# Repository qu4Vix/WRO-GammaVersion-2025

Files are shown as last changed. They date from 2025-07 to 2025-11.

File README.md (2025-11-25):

# WRO 2025 GammaVersion’s repository
**This is our repository for the 2025 season of the WRO Future Engineer Challenge**

***
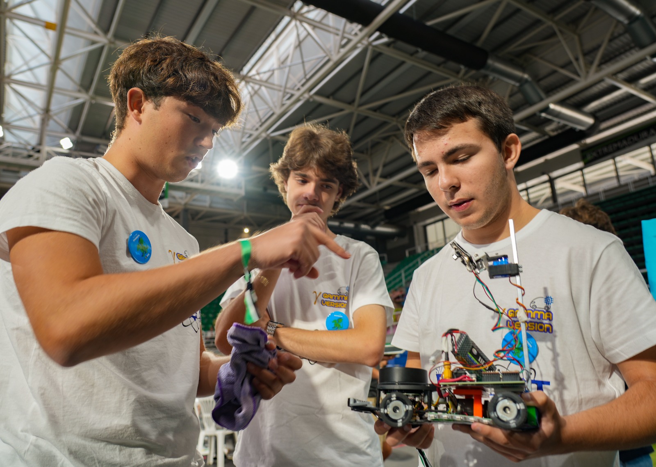
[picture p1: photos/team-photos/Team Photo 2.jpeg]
Picture of our team in the 2025 Spanish National Final


## TABLE OF CONTENTS

* [Hardware](#hardware)
    * [Car movement](#car-movement)
    * [Structural design](#structural-design)

* [Electronics and sensors](#electronics-and-sensors)
    * [List of components](#list-of-components)
    * [Sensor list](#sensor-list)
    * [Power Management](#power-management)
    * [PCB](#pcb)

* [Strategy and operation of the code](#strategy-and-operation-of-the-code)
    * [Slave code](#how-the-slave-code-works)
    * [Location of the robot](#location-of-the-robot-on-the-board)
    * [Open Challenge Strategy](#open-challenge-strategy)
    * [Obstacle Challenge Strategy](#obstacle-challenge-strategy)

* [Photos](#photos)
    * [Car images](#car-images)
    * [Team images](#team-images)

* [Demostration videos](#demonstration-videos)

* [License](#license)

* [Credits](#credits)

* [Contact and Social Media](#contact-and-social-media)
  
Gif Bueno 2

## HARDWARE

Designing a self-driving car for these challenges requires a meticulous design process to achieve an optimal final result that meets the needs of the challenge and the potential obstacles that may arise during the programming process and the competition itself.

In our case, in order to reduce development times and finding it more feasible and simple to rely on existing resources than having to design a new chassis from scratch, we decided to use a remote-controlled car kit that we then modified extensively to adapt it to our particular needs.

### Car movement

We can highlight as the main modification the redesign of the turning system to allow tighter turns, since the original kit was deficient in this aspect and forced us to have to maneuver to be able to turn correctly during the competition and, although this is contemplated in the regulations, it made us lose a lot of time and increased the total complexity of the strategy. The redesign required the creation of new parts that have been designed by ourselves and whose 3D files can be found in our repository in the section [`robot-info`](/robot-info/).We have printed these parts with our 3D printer, which also reduces costs and allows us to easily create different versions if we see that they fail or not.

With these changes to the turning system we have implemented the **Ackerman's Steering Geometry**,this mechanism allows the turning wheels to take different paths when turning, since the turning radius of the inner wheel is smaller than that of the outer wheel, thus the angle of each turning wheel is different. This implementation allows for better turning, and with certain tweaks, we have minimized the required turning radius. This mechanism is actuated by a generic servo **DSM44 Servo**. It has the necessary torque and speed without being a problem in terms of power consumption. In the following images, we can see the nature of why this mechanism is necessary, a simplified version of how it works, and our design of the mechanism for our robot.

| | |
| --- | --- |
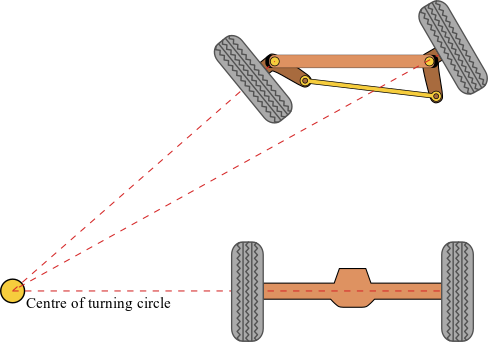
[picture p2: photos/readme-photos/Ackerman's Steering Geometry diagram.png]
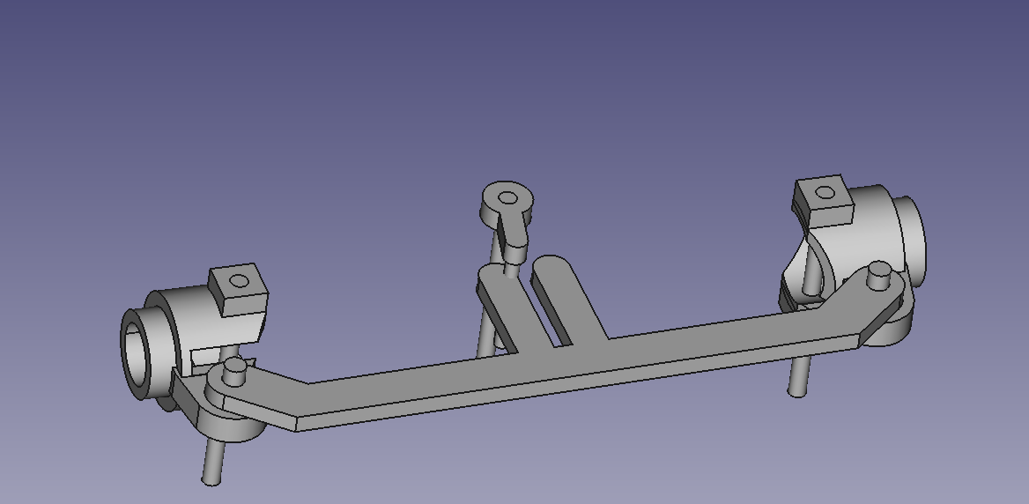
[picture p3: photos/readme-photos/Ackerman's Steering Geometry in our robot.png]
|  |  |

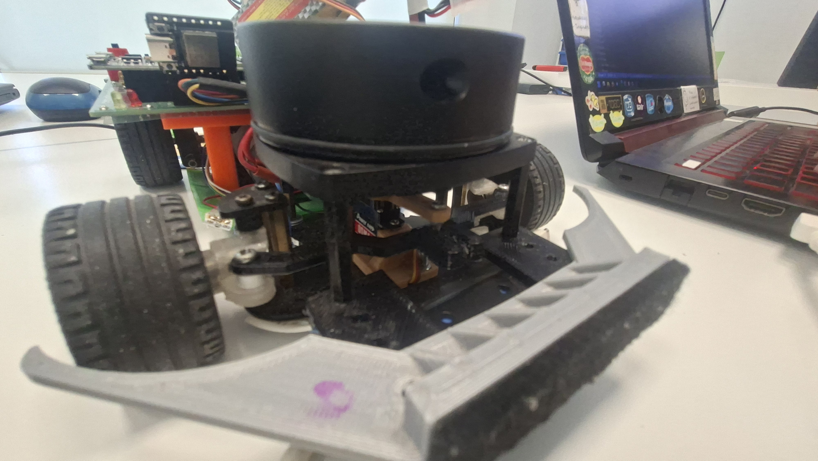
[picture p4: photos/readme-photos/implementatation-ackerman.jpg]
Car front view of the steering design


More information about Ackerman's Steering Geometry can be found in [this Wikipedia article](https://en.wikipedia.org/wiki/Ackermann_steering_geometry).

According to competition regulations, only one motor can drive a drive axle. Therefore, in our case, we made the rear axle the drive axle to which the motor is connected. This is how the original kit was made. We also used the differential that came with the kit for proper operation. The differential allows the rear wheels to travel different distances, since the arc that each wheel travels is different when turning, as the turning radius of each wheel also varies. For our robot, we also used the motor that came with the kit; you can see the image below.

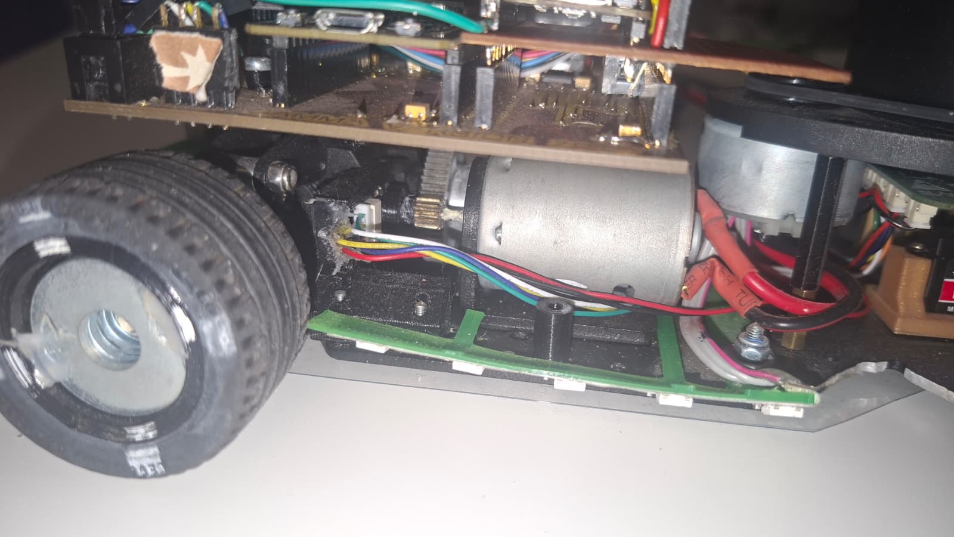
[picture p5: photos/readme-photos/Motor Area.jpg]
Side view of the motor


This motor provides us with the necessary torque to comfortably move the robot without it getting stuck. In our case, we're not trying to get the robot to go at maximum speed, so the robot's overall speed wasn't a relevant factor when choosing the motor.

### Structural design

As we can see in this image, the robot needs to accommodate a variety of different sensors in its limited space. This required a proper structural design beyond the kit's chassis, which is the lower black part of the robot.

First of all, we can distinguish the **LiDAR** Located on the front of the robot, this component rests on the chassis and is bolted to it. It also connects to a front bumper that protects the components in the event of a collision during testing or competition.

Secondly, below the LiDAR is the space needed to place the components of the **Ackerman's Steering Geometry** and the **servo** in charge of turning the wheels.

Thirdly, at the rear we can see from above the **PCB**, which houses much of our car's electronics, further on in [PCB](#pcb) we detail its design. Just below the PCB is the **motor** and the **differential** that drives the drive axle.

Finally, at the rear, the metal mast that raises and holds our **camera** is held on a 3D-designed base to the vehicle.

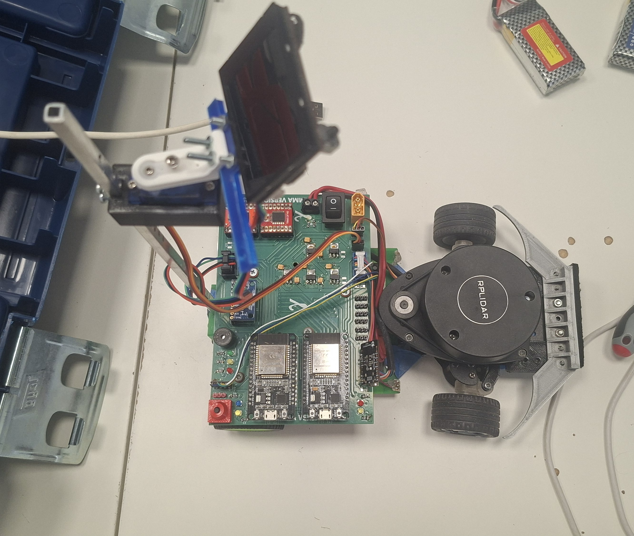
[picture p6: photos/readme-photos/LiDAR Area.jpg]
Top view of the car


## ELECTRONICS AND SENSORS

Our robot is made up of a whole series of electronic components and sensors that work together to provide us with the best possible information so we can perform our tasks. We must emphasize the use of information from multiple sensors simultaneously to reduce errors.

Below we provide a detailed list of all the electronic components that make up the car, along with a detailed description of their functionality and the advantages that led us to use them.

### List of components

* DOIT ESP32 DevKit V1 x2
* HuskyLens
* RPLiDAR A1 M8
* MPU 9250
* Pololu Magnetic Encoder
* DSM44 Servo
* Motor Driver x2
* Power Supply x3
* RGB LEDs
* White LED flashlight

#### Esp-32 (Microcontroller)

To bring our autonomous car project to fruition, we opted for the ESP-32 microcontroller as the central control unit. The ESP-32 boasts several compelling advantages that played a pivotal role in our decision-making process:

1. Computing Power and Versatility: The ESP-32 distinguishes itself with its robust computational capabilities and remarkable versatility. Equipped with a potent dual-core processor and ample memory capacity, it emerged as the natural choice for our robotics endeavor, enabling rapid computation and accommodating our storage needs seamlessly.

2. Advanced Wireless Connectivity: The ESP-32 integrates cutting-edge Wi-Fi and Bluetooth connectivity, positioning it as a frontrunner for efficient wireless communication. This capability empowered us to establish seamless and reliable communication channels between the autonomous car and external devices, a really useful feature for our debugging needs. However, wireless connectivity is forbidden during the competition and we disable this option before the match.

3. Sensor and Actuator Compatibility: The ESP-32's adaptability extends to sensor and actuator integration. With its multitude of I/O (input/output) pins and versatile interface options, we effortlessly connected and controlled various sensors, including the IMU and LiDAR, as well as the steering servos.

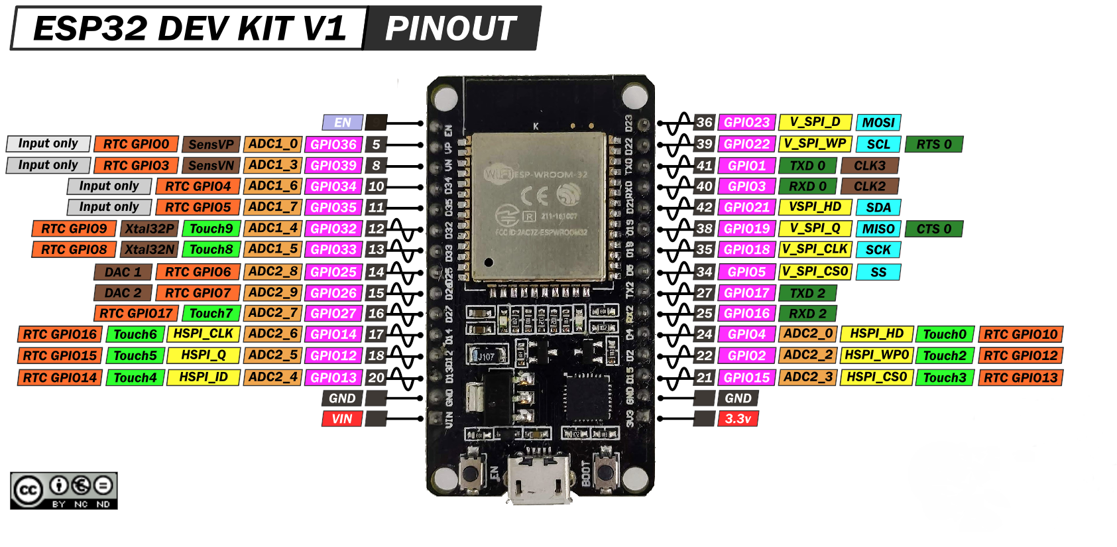
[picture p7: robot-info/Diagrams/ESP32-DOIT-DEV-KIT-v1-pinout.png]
Pinout of the ESP32 DevKit V1


We integrated two ESP32s into our robot, as it was necessary due to the large amount of information they must analyze from all the sensors and the decisions they must make. For this purpose, we call one ESP32 "Slave," to which several sensors are connected. After analyzing this information, it sends it to another ESP32, which we call "Master." Other sensors are connected to this ESP32, and it is responsible for executing all the movement commands.

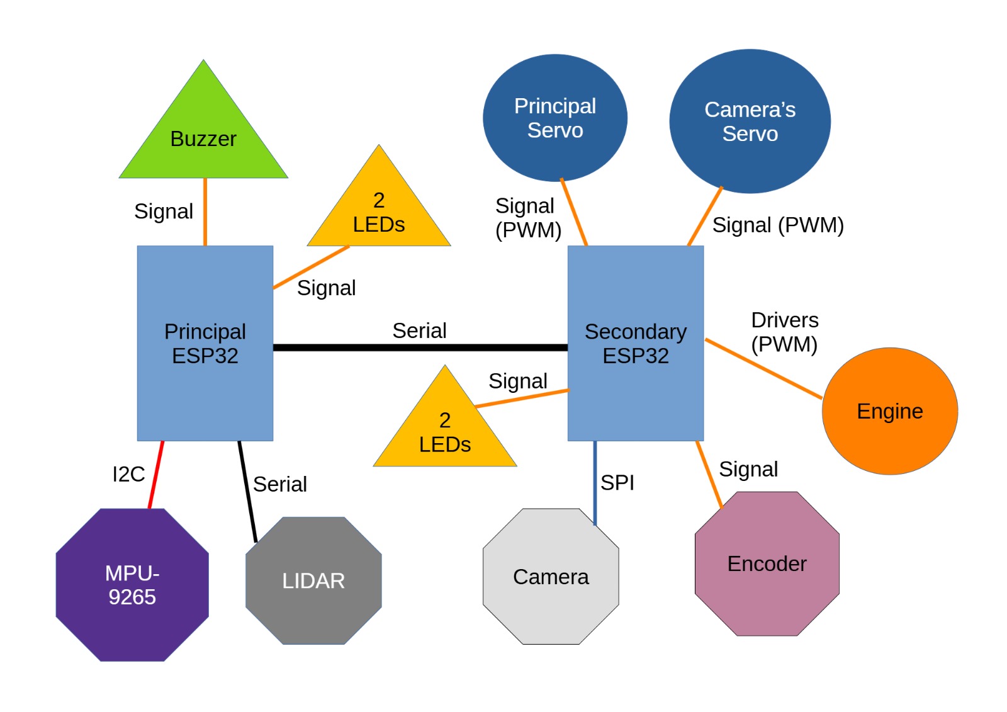
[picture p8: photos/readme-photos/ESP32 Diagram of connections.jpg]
Connection diagram


#### HuskyLens (Camera)

The HuskyLens camera was our choice because it gives us a larger horizontal field of view compared to other available cameras and also incorporates several algorithmic options to be able to detect a wide variety of things, such as distinguishing colors, people, objects, codes, etc. We also chose it because of its improved data processing capacity, which is superior to the alternatives we had locally and which also allows us to train it much better than other cameras, thus guaranteeing a great improvement in precision and allowing us to adjust to the lighting conditions of the competition venue.

The camera's sole function is to detect the colored blocks, indicate their position on the camera, and indicate their color. We train it for all of this before the competition.

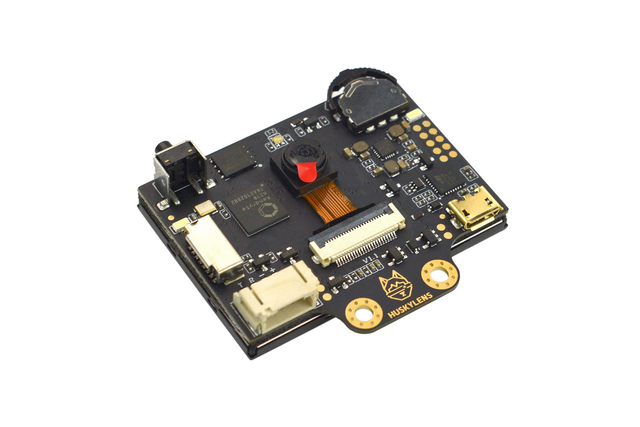
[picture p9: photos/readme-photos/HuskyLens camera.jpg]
Image of a HUSKY Lens


#### RPLiDAR A1 M8 (LiDAR)

Rather than relying on traditional ultrasonic sensors for obstacle detection, we opted for LiDAR technology. LiDAR, which stands for Light Detection and Ranging, uses laser beams to measure distances to objects with exceptional precision. This technology offers several advantages over ultrasonic sensors:

1. Greater Range: LiDAR can detect objects at much greater distances, providing the car with more time to react to potential obstacles.

2. High Precision: LiDAR provides accurate distance measurements, resulting in better navigation and collision avoidance.

3. 360-Degree Coverage: LiDAR offers a full 360-degree view around the car, ensuring comprehensive situational awareness.

4. Environmental Adaptability: LiDAR is less affected by environmental factors such as ambient light, making it more reliable in various conditions.

During the match the LiDAR technology is used to establish the initial position of the robot and the direction of the game. In this way the random initial conditions do not affect the outcome of the match.

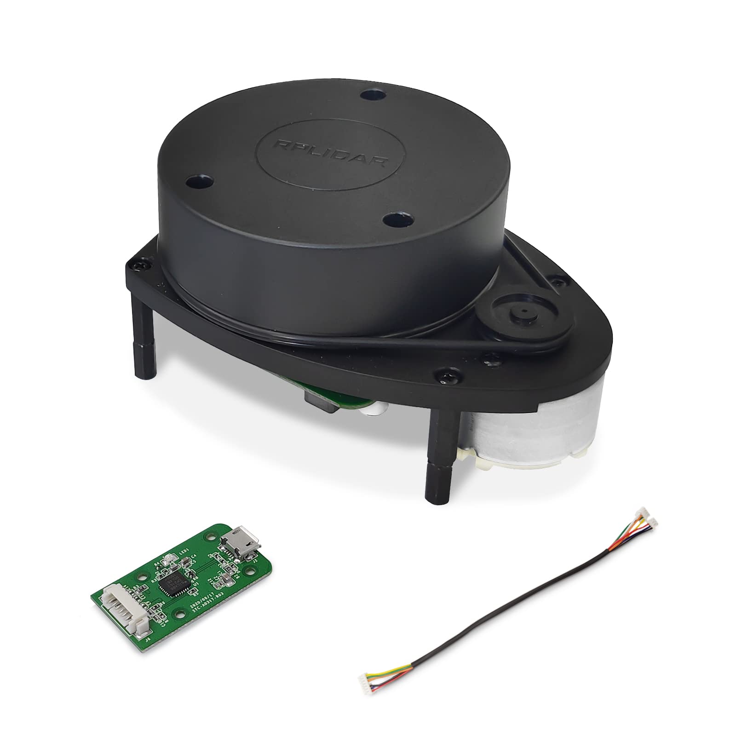
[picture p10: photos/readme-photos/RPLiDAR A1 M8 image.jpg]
Image of an RPLIDAR A1


#### MPU 9250 and Pololu Magnetic Encoder (IMU and encoder)

On one hand, IMU stands for Inertial Measurement Unit, this is a combination of gyroscopes, accelerometers and in our MPU 9250 magnetometers too. On the other hand, a enconder is a system that reads the rotation of the motor or axle and allows us to know how much it has turned, and with some analysis it lets us know the length of the displacement of our robot. Inertial navigation has plenty of disadvantages compared to for example LiDAR navigation, some of its problems are that the precision is worse than LiDAR's and that this system does not really know where the robot is in the real world, only how much it has moved or turned since the start of the program. It might seem that using this technology is a downgrade and unnecessary as we already have the LiDAR, however, the IMU combinated with a encoder gives easier-to-use data compared to the huge amount of information the LiDAR gives us every second.

In our case, we only use our LiDAR to establish which is the initial position of the robot and the direction of the game, but after this the LiDAR is no longer used in the game. Through all the rest of the match only the IMU and encoder are used to follow an imaginary path around the central square in the Open Challenge or around the square and through the traffic signs in the Obstacle Challenge with the color information gived by the camera.

#### White LED flashlight

Shortly before attending the Spanish national final, we observed that in certain situations with changing lighting, our robot could have serious problems distinguishing colors. The fact that our camera is sensitive to light was already known, but we didn't think it would be so problematic at first. However, seeing that it was causing problems and with limited time, we decided to install a white LED light next to the camera so that it would receive video with a constant amount of illumination at all times.

The LED was connected directly to the battery and main power switch, ensuring that the power consumption of the LED  wouldn't negatively impact other more sensitive systems in the robot. To prevent the LED from receiving too much current, several resistors were installed in parallel along the cable.

After the competition, we analyzed that the camera still had occasional problems, and we eventually redesigned the camera's code to avoid these issues. Our robot still has the space and components necessary to reinstall the LED if we deem it necessary during the competition, although, as we have already mentioned, this shouldn't be the case.

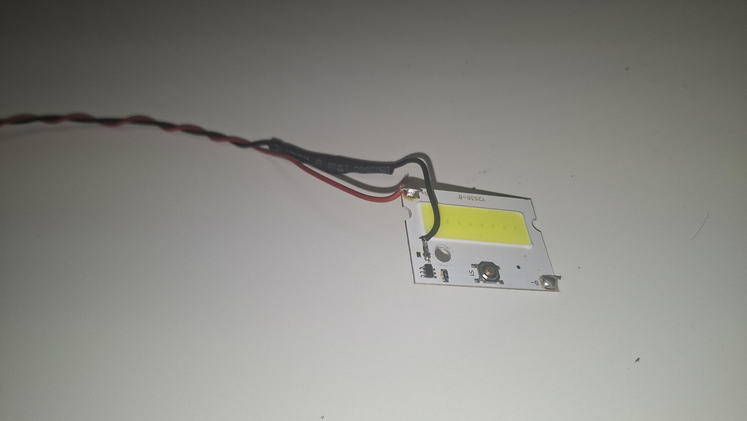
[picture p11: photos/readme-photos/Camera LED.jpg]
Image of the camera's LED lantern


### Sensor list

As we can see, our robot only uses the following sensors, whose data are used in unison by our microcontrollers to maximize reliability and be able to solve the different challenges that this competition poses to us.

* LiDAR
* IMU
* Encoder
* Camera

### Power Management

Our robot is powered by a single 7V battery with a capacity of 1200 mAh, which provides the necessary energy for the robot to function properly. Before building the car, when we were considering which electronic components to choose, we considered the energy consumption of each component and how we could provide the necessary voltage to each element. After analyzing this, we designed the system to adequately meet the energy requirements.

Our PCB contains several power sources that distribute power correctly and efficiently to our sensors and actuators. We can list them as follows:

1. Dual 5-Volt Power Supplies: One 5-volt power supply was dedicated to powering the LiDAR system, while the other supplied power to the steering servos. This separation of power sources allowed us to optimize the energy delivery to these critical components, ensuring their reliable operation.

2. 3.3-Volt Power Supply: A dedicated 3.3-volt power supply was employed to energize the microcontrollers, IMU (Inertial Measurement Unit), motor drivers, and LED lights. This voltage level was carefully chosen to meet the requirements of these electronic components, guaranteeing stable and consistent performance.

By employing these distinct power sources, we effectively managed the power needs of our autonomous car's various subsystems, ensuring that each component received the appropriate voltage and current for reliable operation. This meticulous power management contributed to the overall success and stability of our robotics project.

### PCB

To seamlessly connect and control all the components of our autonomous car, we designed and printed a custom PCB. The PCB acted as the central hub that allowed us to interface with sensors, motors, microcontrollers, and other electronic components efficiently.

Our custom PCB design allowed for cleaner wiring, reduced interference, and enhanced reliability. It simplified the process of connecting and configuring various sensors and actuators, enabling smoother integration and troubleshooting during the development phase.

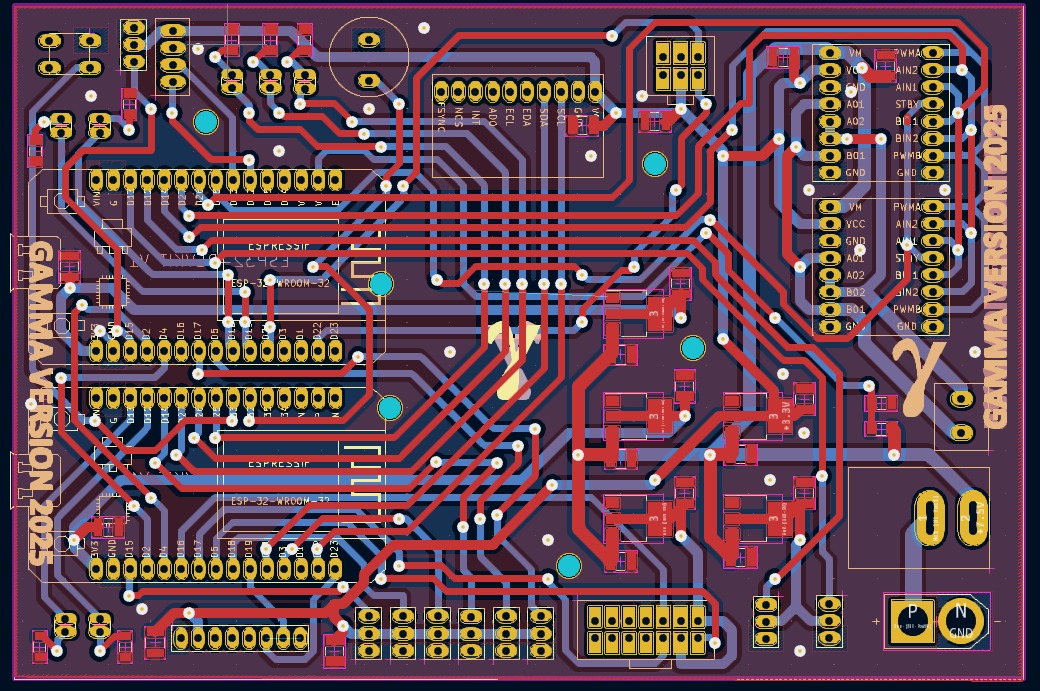
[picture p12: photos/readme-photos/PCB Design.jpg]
Layer design image of the PCB


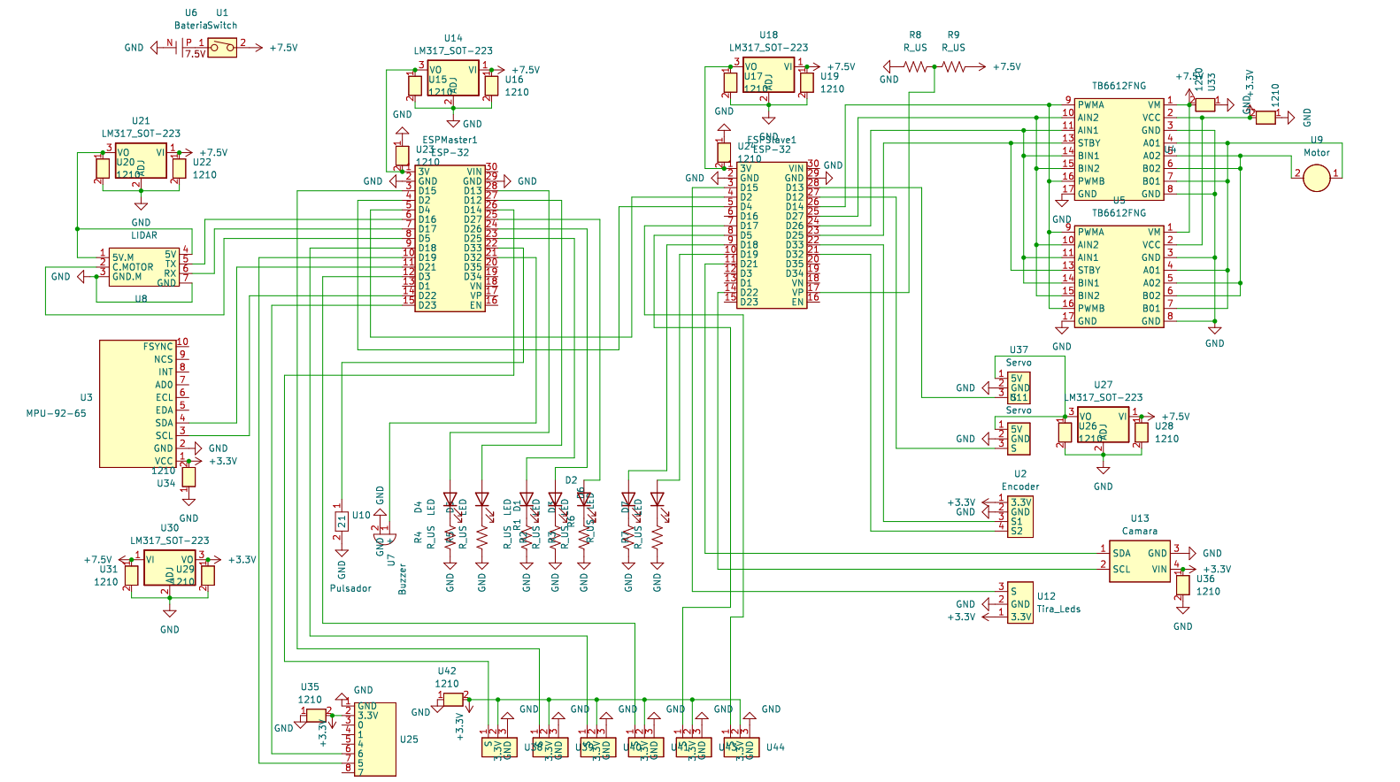
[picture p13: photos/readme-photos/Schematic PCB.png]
Schematic diagram of the circuit


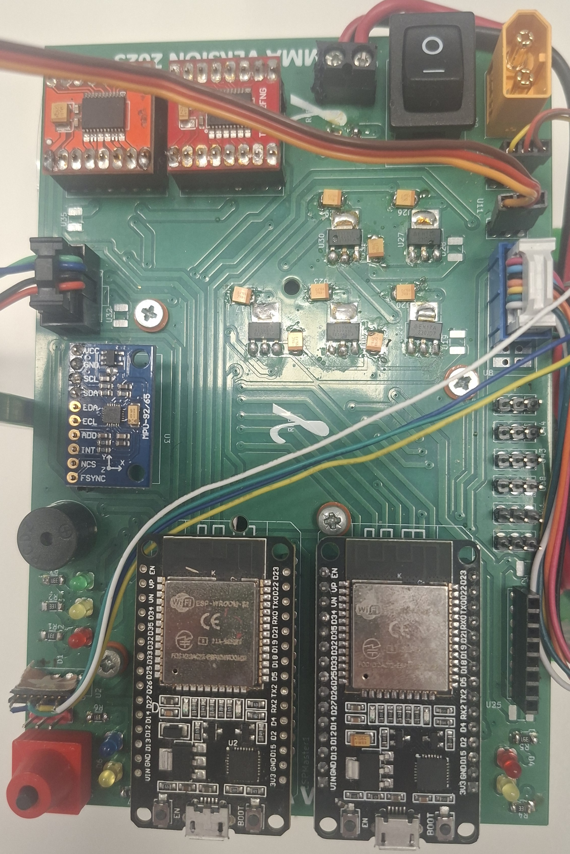
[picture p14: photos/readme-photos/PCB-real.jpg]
Top view of the finished PCB


## STRATEGY AND OPERATION OF THE CODE

As we mentioned before, the code is divided into two parts, one for the ESP32 “Master” and another for the ESP32 “Slave”. In our case, the code for the “Slave” is the same for both types of rounds in the competition, the Open Challenge and the Obstacle Challenge. If you wish, you can activate or deactivate certain functions related to the Obstacle Challenge when not in use by changing a value of a define in the code, although this is not necessary for correct operation.

On the other hand, due to the large variations between the two challenges, we found two separate codes for the ESP32 "Master," one used only in the Open Challenge rounds and the other for the Obstacle Challenge rounds. This gives us two separate codes that allow us to better address the bugs and challenges of each category.

For more information on the code structure and the upload protocol, go to [code](code/README.md).

### How the “Slave” code works

The “Slave” code is responsible for collecting data from various sensors and sending it via serial to the “Master” for processing and analysis. On the other hand, the “Slave” receives data via serial to move the motor and servo from the “Master”.

The "Slave" also has the function of cleaning and filtering the camera information. Due to the way the HuskyLens works, it is very likely that it will mistakenly detect the orange line on the dashboard as if it were a red block, or even detect the parking barriers as red blocks. This is clearly detrimental to the robot's operation and can lead to errors. To avoid these errors, the "Slave" only sends to the "Master" the block that is closest to the camera and that is not a square or a horizontal rectangle (this is because the camera detects objects in squares that encompass the surface of the detected object, not the object's actual shape). This prevents detection errors.

### Location of the robot on the board

To determine the car's exact location on the dashboard, the same system is used in both the Open Challenge and the Obstacle Challenge. The system is based on a coordinate system that places (0,0) in the lower left corner from the car's point of view. To locate the car on the dashboard, two phases occur:

1. From the robot's starting location, the LiDAR measures the distance in a straight line from the robot to the front wall, that is, at an angle of 0° relative to the robot's current direction. With this data, we can determine the robot's current Y-position.

2. The robot then moves forward until it is a certain distance from the front wall that allows it to see to the sides. The robot now measures the distance to its left (270°) and right (90°). With this data, the robot is able to establish its position on the X axis of the coordinate system, and it also allows it to determine the direction of rotation of the circle.

### Open Challenge Strategy

In the Open Challenge, the robot must complete three laps of the circuit from a random starting position and direction and must be able to finish in the same starting section. In addition, the size of the central square varies from round to round, adding additional difficulty.

With the information from the previous paragraph in mind, our strategy is based on correctly determining our position on the board and then completing the circuit from there. Our robot has no knowledge of the size of the central square, as it simply navigates an imaginary circuit that is larger than the maximum limits of the central square, as we can see in the images.

| | |
| --- | --- |
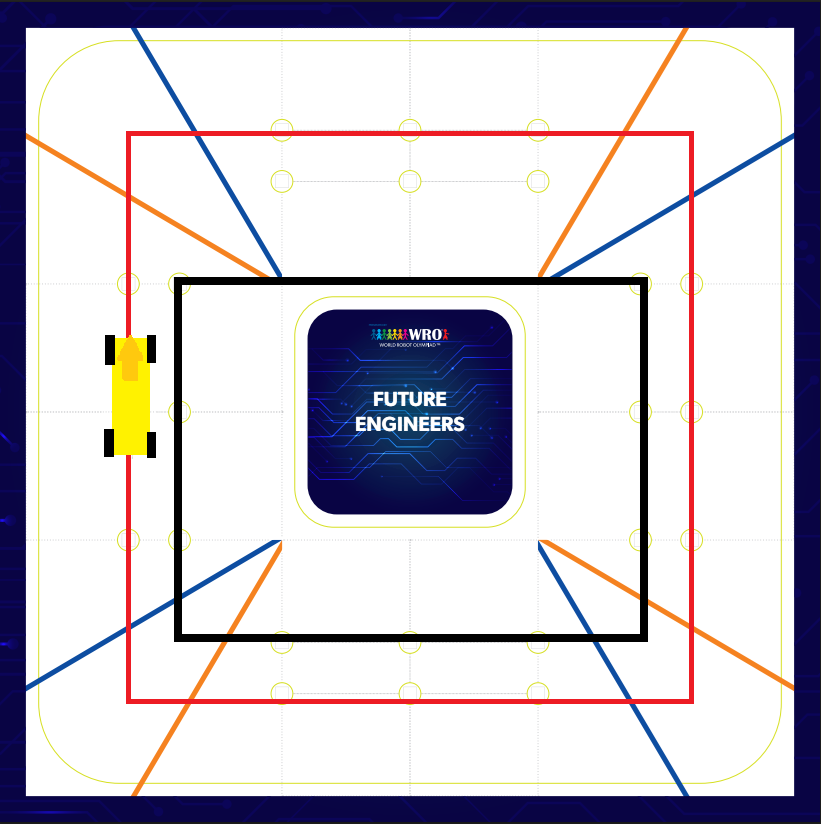
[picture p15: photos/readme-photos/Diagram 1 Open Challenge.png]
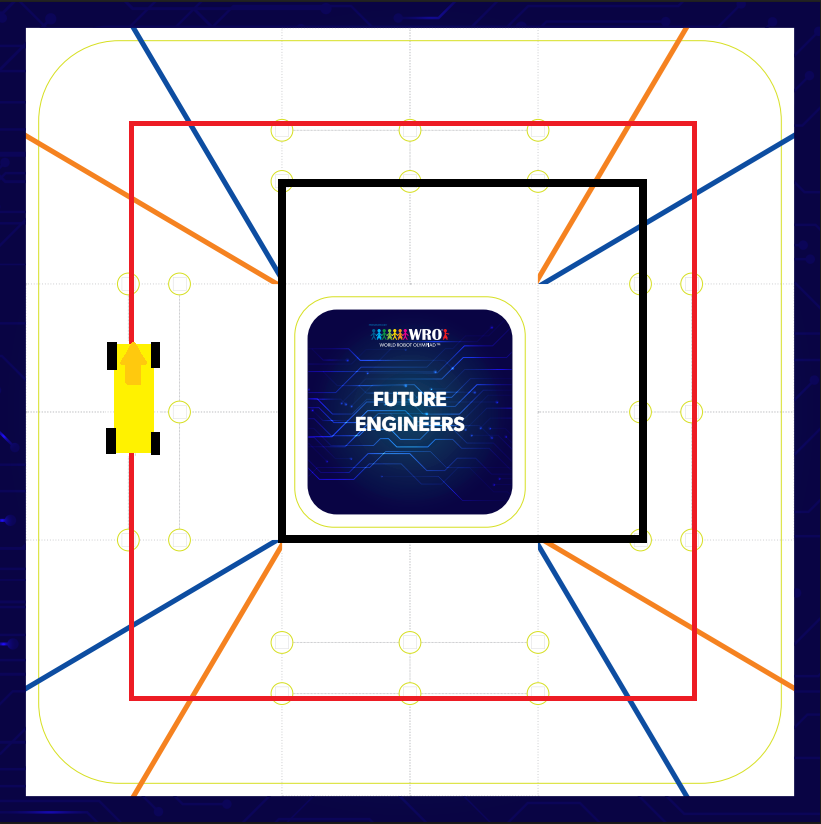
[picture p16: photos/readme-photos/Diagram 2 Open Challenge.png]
|  |  |

### Obstacle Challenge Strategy

The goal in the Obstacle Challenge is for the robot to complete three laps of the circuit, dodging the green blocks or "traffic lights" on the left and the red blocks on the right without colliding with them or making any mistakes. To earn more points, you can optionally start from the parking area (defined by two horizontal barriers) instead of the middle of the board. You can also optionally park inside the parking area, earning even more points if you parallel park.

Our code is designed to always start from the parking area. Therefore, at the beginning of each round, we use LiDAR to measure both sides of the robot (left and right) to determine the greater distance. If the distance is greater to the right than to the left, the robot knows the direction of rotation is clockwise, while if it detects a greater distance to the left, it knows the direction is counterclockwise. Once we know the direction of rotation, we use the distance to the central wall to establish our position on the board, following our own system that we discussed earlier. The algorithm is as follows:

* If (Clockwise == True) PositionX = 1000 – LiDAR_Measurement (90º);
* If (Clockwise == True) PositionX = 2000 + LiDAR_Measurement (270º);

Knowing the X position, the robot is now able to leave the parking area. However, to prevent accidentally passing a traffic light immediately after exiting, the camera's servo motor points directly to where a block might be located, to check for its presence.

Before continuing, it's important to explain several key aspects of how our code works:

* First, we designed a complex and useful automatic movement system where we tell the robot which X and Y position we want it to move to, and it performs the movement on its own. This way, if you look at our code, you'll see that we rarely send commands directly to the motors or the wheel servo, but rather to the movement instructions. The movement is complemented by a PID controller with KD and KP values that we can vary along the robot's path as needed.

* Second, internally we divide the board into four "sections" that represent each non-turning section.
* Third, our robot never considers whether the blocks are in the inner or outer squares; whenever it sees a block, it will avoid it in such a way that it never crosses any square.

Having said that, to exit the parking area, we programmed our motion system to leave by assigning it coordinates located next to the parking lot. Once this was done, we used LiDAR to measure the external barrier above the robot. We used trigonometry so that even if the robot wasn't 100% parallel or perpendicular to the upper barrier, it would still provide correct directions, regardless of whether the robot was slightly tilted relative to the barrier.

If there had been a block upon exiting the parking area, the robot would have avoided it. After exiting and avoiding the block, if necessary, the code would enter the "avoid and learn" state. In this state, the robot completed one lap of the circuit, reading the colors of the blocks with the camera and avoiding them on the correct side.

Because the wide-angle lens of our camera wasn't very good, we decided to install a servo motor underneath the camera to move it and ensure that the camera always pointed where blocks might be. This mechanism is really important for tight turns, where there's a chance that if the camera were fixed, the robot wouldn't see the next block before missing it or crashing.

In this first "state," in addition to reading the camera, the robot is memorizing the position of each traffic light. After completing the first lap, the robot performs the next two laps "from memory," without using the camera at any point. We do this because every time we measure the blocks with the camera, there's a small chance the robot will make a mistake. It's true that it can also make a mistake on the first lap, but if this happens, we would have already finished the lap, as it ends as soon as a mistake is made, according to the regulations. If we haven't stopped after the first lap, it means we already know the position of the traffic lights well, so it's best to perform them from memory instead of continuing to maintain the probability of error.

When the robot reaches the last corner of each lap, it stops, remaining perpendicular to the external barrier in front of it, to recalibrate its position using LiDAR. We didn't originally intend to do this, but after extensive testing, we realized that the IMU and encoder lost accuracy and quality throughout the lap, especially if the robot had to perform many maneuvers.

Finally, after the three laps and the final recalibration, the robot enters "parking" mode. It then slowly approaches the parking position, maneuvers back slowly, and finally parks. In this mode, we significantly increased the turning radius (KP) and turning radius (KD) to maximize the robot's turning capabilities and enable it to park in the limited available space.

## PHOTOS

### Car images

| | |
| --- | --- |
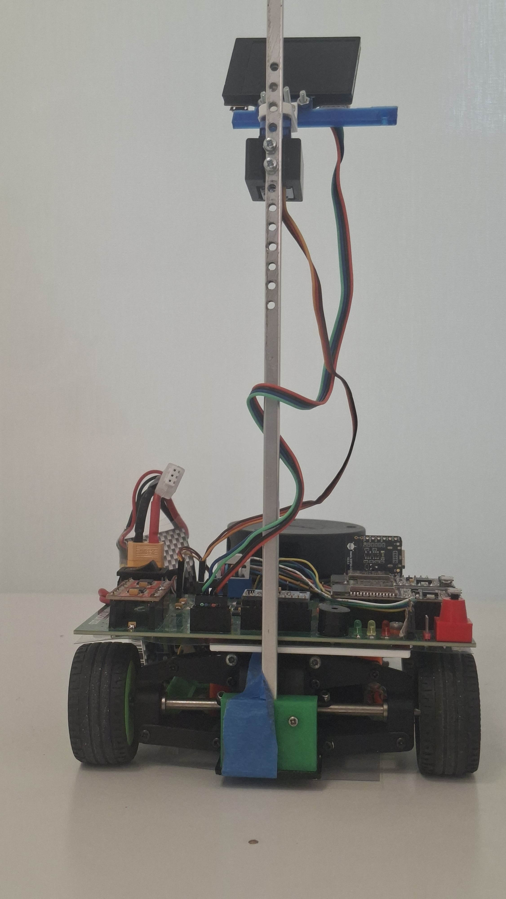
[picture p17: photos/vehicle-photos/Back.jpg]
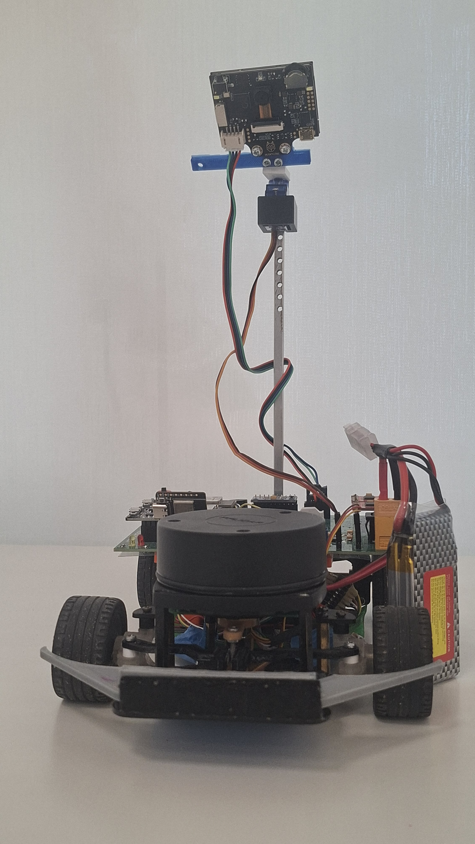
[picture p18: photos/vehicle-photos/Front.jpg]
|   |  |
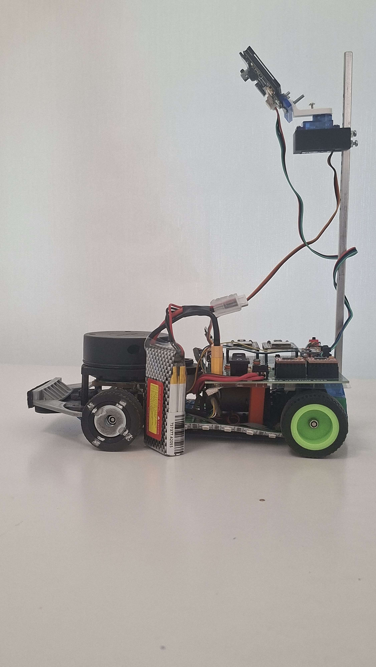
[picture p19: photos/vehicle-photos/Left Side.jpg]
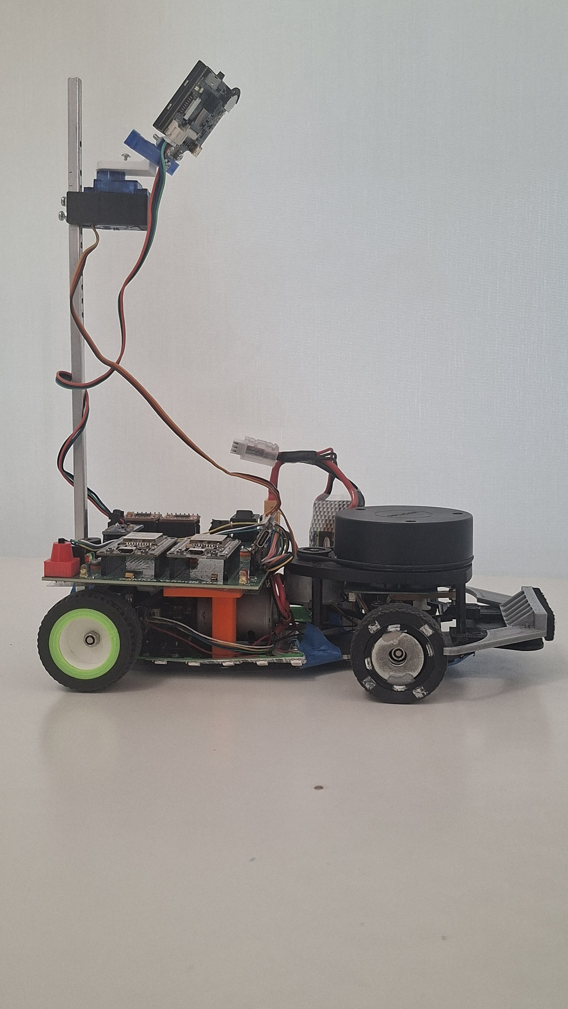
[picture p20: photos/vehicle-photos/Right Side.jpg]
|  |  |
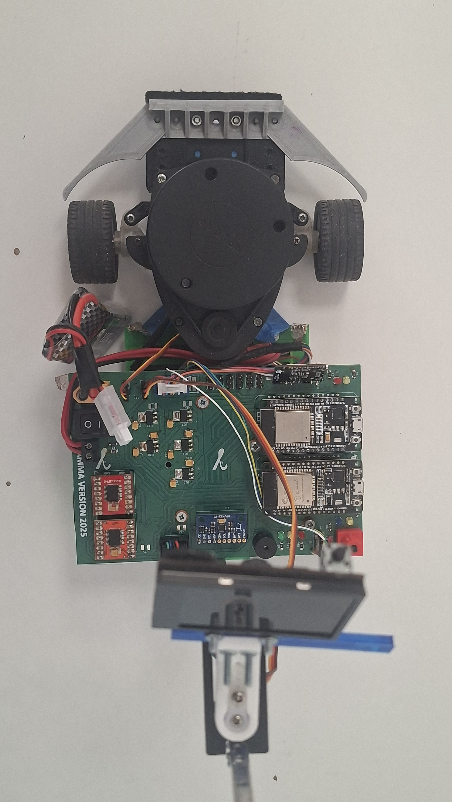
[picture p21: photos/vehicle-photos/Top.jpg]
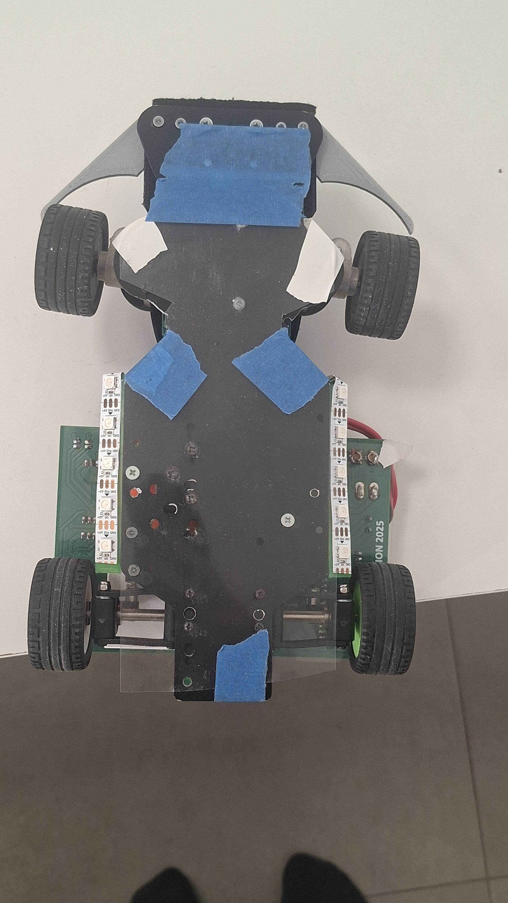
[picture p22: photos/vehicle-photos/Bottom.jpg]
|  |  |

### Team images

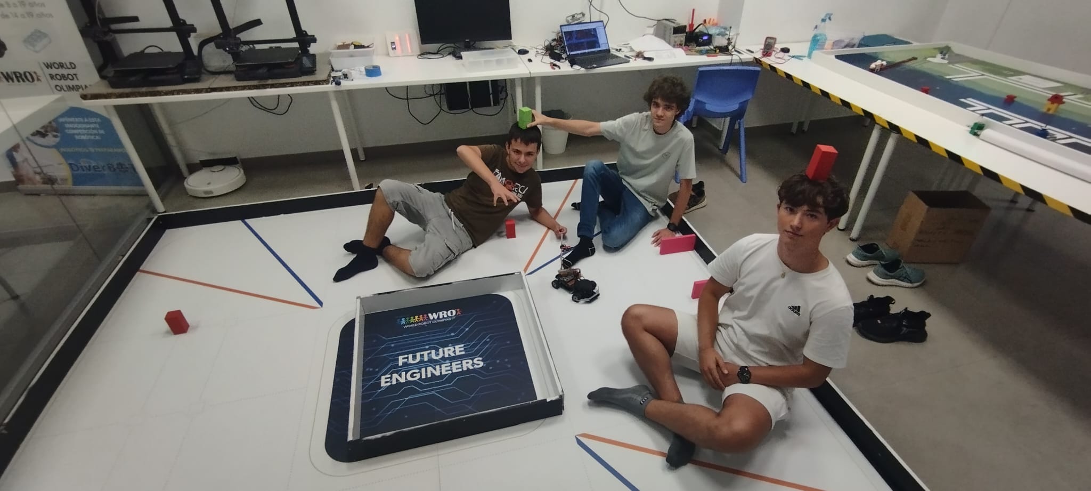
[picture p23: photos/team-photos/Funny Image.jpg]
Funny photo of the team


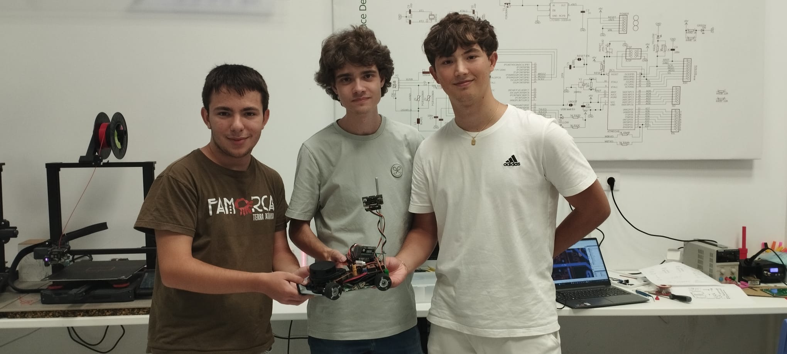
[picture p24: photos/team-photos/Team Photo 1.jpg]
Official team photo


Our team in the National Final

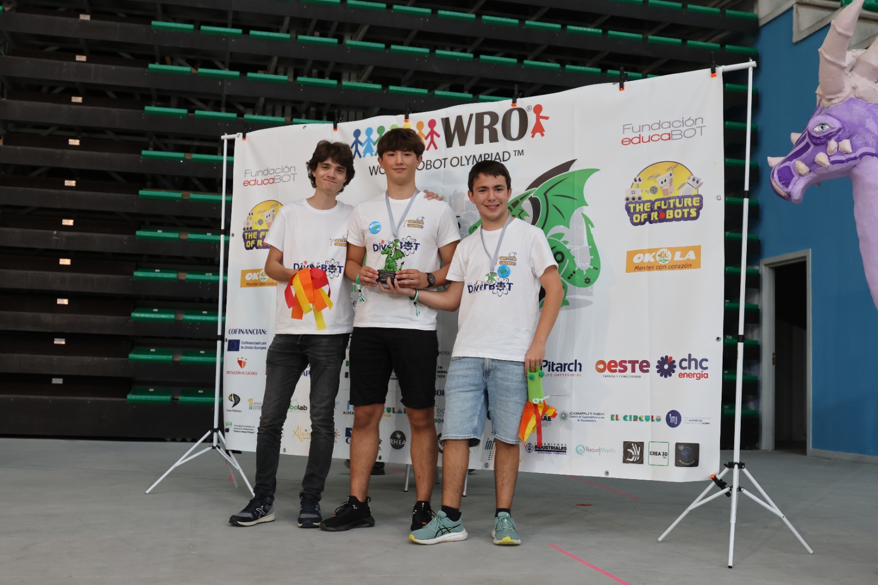
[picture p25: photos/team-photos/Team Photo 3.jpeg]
Our team holding the Spanish champions trophy


## DEMONSTRATION VIDEOS

Demonstration videos of the car successfully completing both challenges. The links to each of them can be found in:

* [Open Challenge](https://youtu.be/jVDG6yYy9Xo)
* [Obstacle Challenge](https://youtu.be/SR2mRw_vzmI)

MORE VIDEOS IN OUR [YOUTUBE CHANNEL](https://www.youtube.com/@gammaversion)

## LICENSE

The [source code](/code/) in this repository is licensed under the **GNU General Public License v3.0**.

The [hardware](/robot-info/hardware/) exposed in this project is licensed under the **Creative Commons Attribution Share Alike 4.0 International** license.

The documentation of this repository; found in [`robot-info`](/robot-info/), [`vehicle-photos`](/photos/vehicle-photos/), [`videos`](/videos/), [`team-photos`](/photos/team-photos/), as well as this `README.md`; is licensed under the **CERN Open Hardware Licence Version 2 - Strongly Reciprocal** license.

A copy of each license can be found in the [LICENSE](LICENSE) file. More information about the licenses in the specific README.md of each section.

## CONTACT AND SOCIAL MEDIA

This year, as we approached this challenge once again, we decided to resume our presence on social media through our Instagram account ([@gammaversiondiverbot](https://www.instagram.com/gammaversiondiverbot/)). With this account, we have been actively sharing our progress and journey from the beginning to the present day.

Furthermore, immediately after winning the WRO 2025 National Final in Spain we launched a website to showcase our team more openly and professionally, especially to find sponsors willing to help us cover the costs of traveling to Singapore. We share this website with another team from our academy that also participates in the competition under the name "Alfa Centauri."

In addition to seeking companies and entrepreneurs willing to support us, we created a crowdfunding page on the [gofundme.com](https://www.gofundme.com/f/ayudanos-a-llegar-a-Singapur-tu-aporte-suma) platform to more easily receive donations from individuals. Finally, we've created a small raffle where we're giving away a laptop with the aim of raising a little more funding and involving the community in the project.

We have also appeared on several local and regional newspaper, radio stations and TV programs

HERE ARE OUR CONTACT AND DISSEMINATION PLATFORMS

*(To attract a local audience, some information on these sites is in Spanish.)*

* INSTAGRAM: [@gammaversiondiverbot](https://www.instagram.com/gammaversiondiverbot/)
* WEBPAGE [singapur2025.diverbot.es](http://singapur2025.diverbot.es/)
* CROWDFUNDING: [gofundme.com/f/ayudanos-a-llegar-a-Singapur-tu-aporte-suma](https://www.gofundme.com/f/ayudanos-a-llegar-a-Singapur-tu-aporte-suma)

## CREDITS

We would like to thank DiverBOT and its team Javier and Ana for their help given to this project.

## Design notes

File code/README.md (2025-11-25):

# Code

This folder contains the code for our car.
The code is structured in Platform IO projects. Each microcontroller has its own project, each of which should be uploaded to the corresdponding micro.

## Platform IO

Platform IO is an extension for Visual Studio Code, which enables uploading arduino framework code to a compatible microcontroller, in our case either of our Espressif ESP32 Devkit V1. Platform IO can be installed by opening Visual Studio's extensions tab, searching "PlatformIO IDE" in the Marketplace Search box, clicking on it and then on the blue "Install" button.

### Uploading the code

For uploading the code, open the appropiate project, depending on the ESP32 that you want to flash and the Challenge that you wish to face. Connect the ESP32 correspondingly via a mirco USB cable to USB, through which the binary will be sent. When you open a platform IO project, the extension detects the platformio.ini file int the folder and automatically activates itself. When PlatformIO is active, an Upload button apperas on Visual Studio's bottom toolbar, which has the appearence of an arrow pointing right. Click on it and a terminal will open indicating the upload process. PlatformIO should automatically detect the COM serial designated and use it to upload the code to the ESP32. In case of an incorrect COM serial being used, select it manually by using the toolbar button with a cable in it and choosing the correct COM. If the upload process errors with message ESP32 in wrong bootmode, it may be solved by pressing the ESP32's BOOT button on upload. If the error message is could not connect to ESP32, check the connection and the upload port.

## Folders

* **Official** This folder contains the main code of our project, which is to be uploaded for the official rounds of the competition. It is divided in 3 projects, one for the "Slave" ESP32 and two -one for each challenge- for the "Master" ESP32.
* **Extras** Here we save the code for tests, extras, tuning programs and telemetry senders, receivers and managers -which are here since telemetry is not allowed during official rounds-.
* **Libraries** Directory intended for general, shared code. Pin assignment headers can be located here, which define each usable pin of the ESP32s in our car. The mpu code, which is shared between both official "Master" projects, is located here for sinchronous updates.

## Projects

* **ESP32 Master**. Controls the main algorithm, the lidar, the mpu and the telemetry. It communicates with the ESP32 Slave through the serial 1 and with the ESP32 Telemetry through serial 0.
* **ESP32 Slave**. Controls most of the hardware: the motors, the servo, the camera, the encoder and the battery. It communicates through serial 1 with the ESP32 Master.
* **ESP32 Telemetry**. Receives data from the ESP32 Master and sends it through WiFi to a computer. This part is for feedback purposes only, hence it is disabled during official rounds by removing the Beetle unit, to comply with the rules of the competition.

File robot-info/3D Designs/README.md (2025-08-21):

## Models
In this folder you can find all the models used in our robot. All the components were designed by us using programs like Freecad or Tinkercad.
***
### Supports
In the [supports](/Supports/) folder, you can find all the supports made for hold diferent parts of the robot, such as sensors or the PCB.
***
### Steering
And the [steering](/Steering/) folder, contains all the models used for the new steering system designed specialy for increase the steering angle.
***

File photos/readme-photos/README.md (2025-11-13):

# README PHOTOS

In this folder, you'll find the various photographs used in the main README.md file of the repository, with the exception of the photos of the robot's sides, which are located in the vehicle-photos folder.

Here you'll also find the original version of the README.md document, which we used for several months before replacing it with the current version, as well as the various photographs that were used as placeholders. We keep all of this here for project archiving purposes.

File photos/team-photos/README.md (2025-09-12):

# Team photos
The team photos are available at this folder. We can find both an official and more "formal" imaga and a "informal" funny photo.

| | |
| --- | --- |
|  |  |

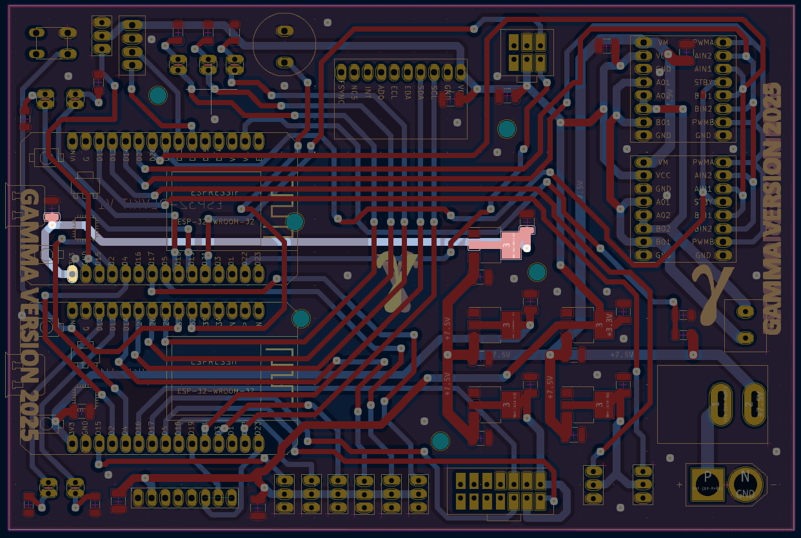
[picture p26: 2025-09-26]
robot-info/Hardware/PCB/Photos&more/3,3VSlavenet.png

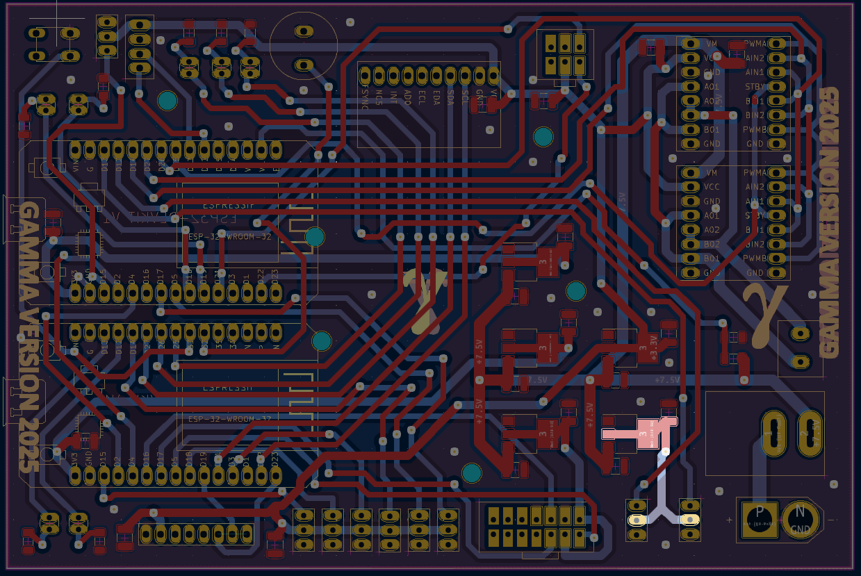
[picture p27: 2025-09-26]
robot-info/Hardware/PCB/Photos&more/5VServosnet.png

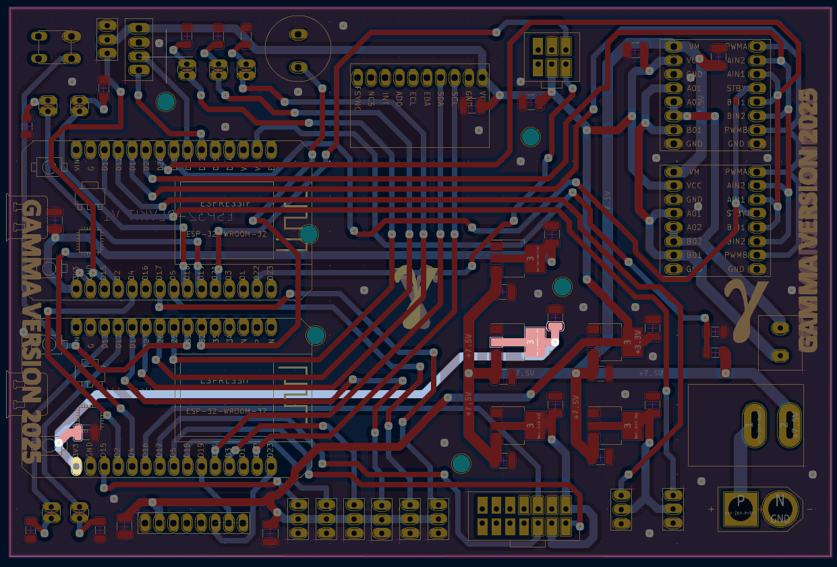
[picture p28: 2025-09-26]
robot-info/Hardware/PCB/Photos&more/3,3VMasternet.png

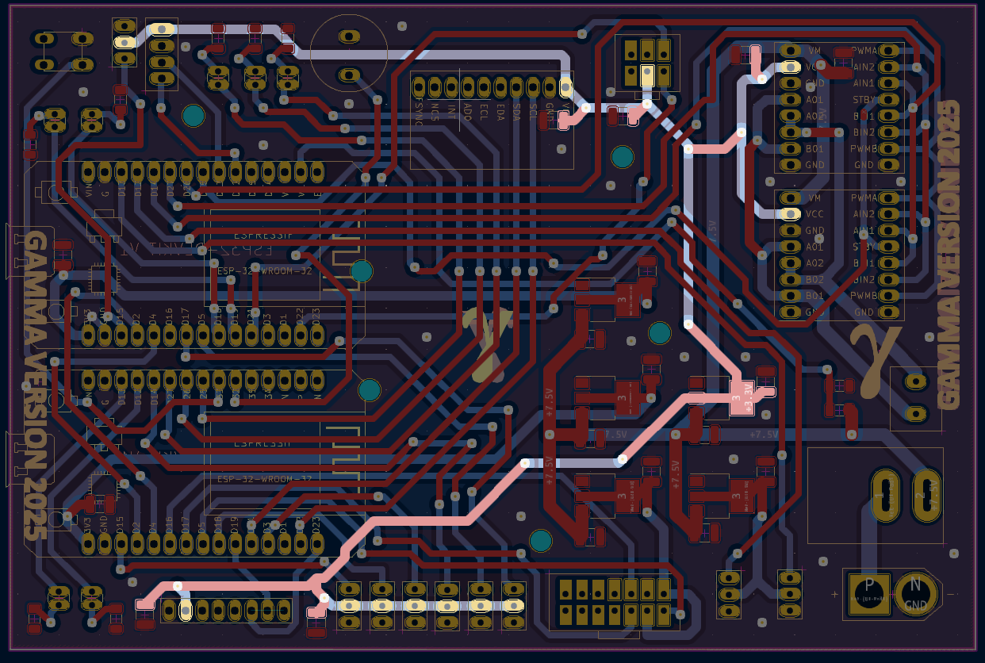
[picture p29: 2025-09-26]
robot-info/Hardware/PCB/Photos&more/3,3Vnet.png

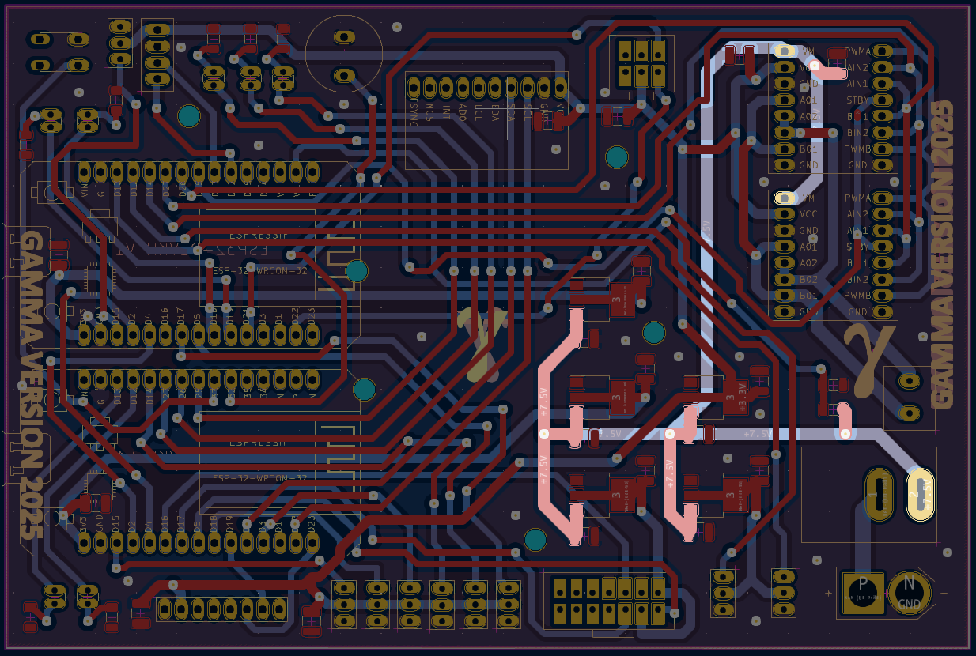
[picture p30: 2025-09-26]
robot-info/Hardware/PCB/Photos&more/7Vnet.png

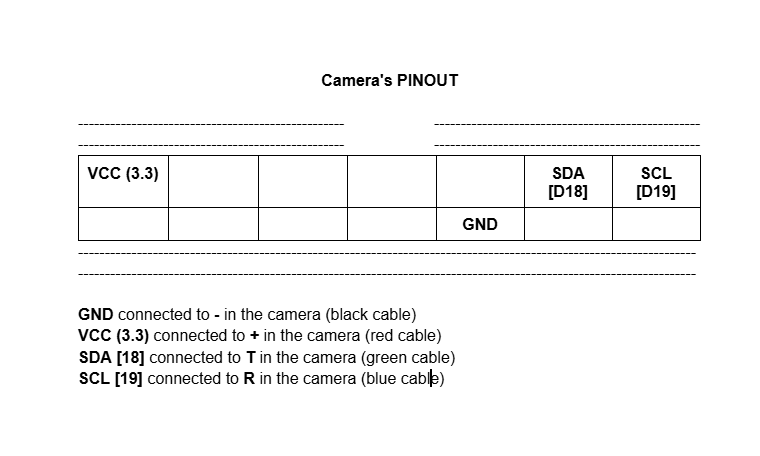
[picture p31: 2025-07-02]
robot-info/Diagrams/Camera's Connector Pinout.png

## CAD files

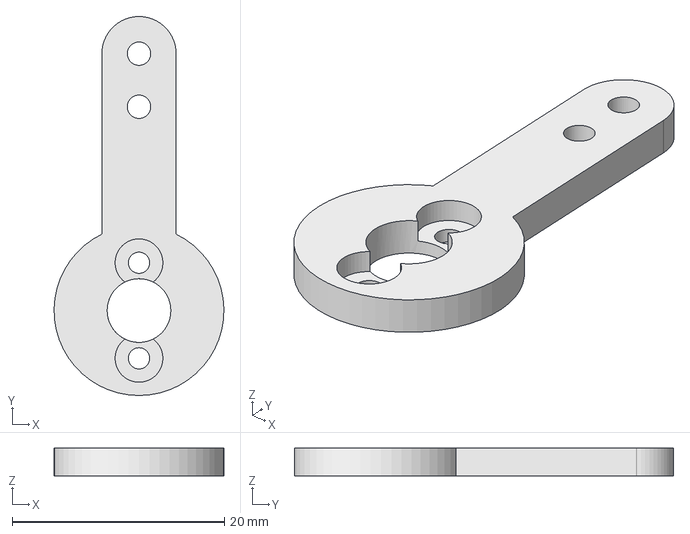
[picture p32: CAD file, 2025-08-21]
robot-info/3D Designs/Steering/FreecadFiles/ServoArm.FCStd
16.0 x 35.7 x 2.60 mm

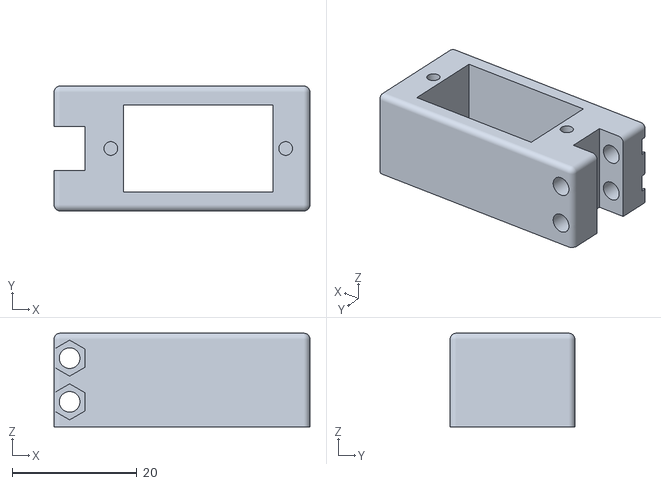
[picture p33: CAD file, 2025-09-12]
robot-info/3D Designs/Supports/CameraAndServoGirado.stl
41.0 x 20.0 x 15.0

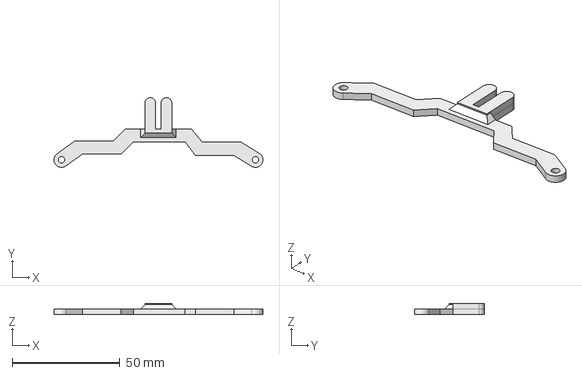
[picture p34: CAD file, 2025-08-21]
robot-info/3D Designs/Steering/FreecadFiles/SteeringArm.FCStd
97.0 x 32.4 x 5.00 mm

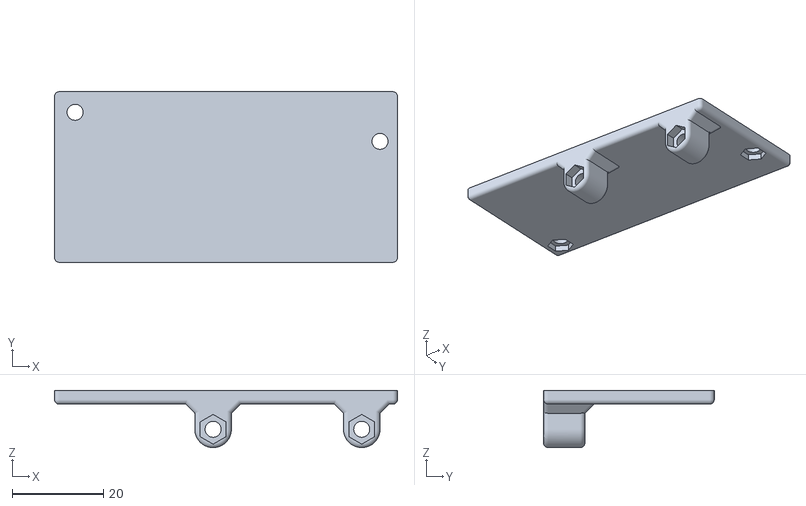
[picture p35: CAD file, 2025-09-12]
robot-info/3D Designs/Supports/BackPCBSupport.stl
75.0 x 37.3 x 12.5

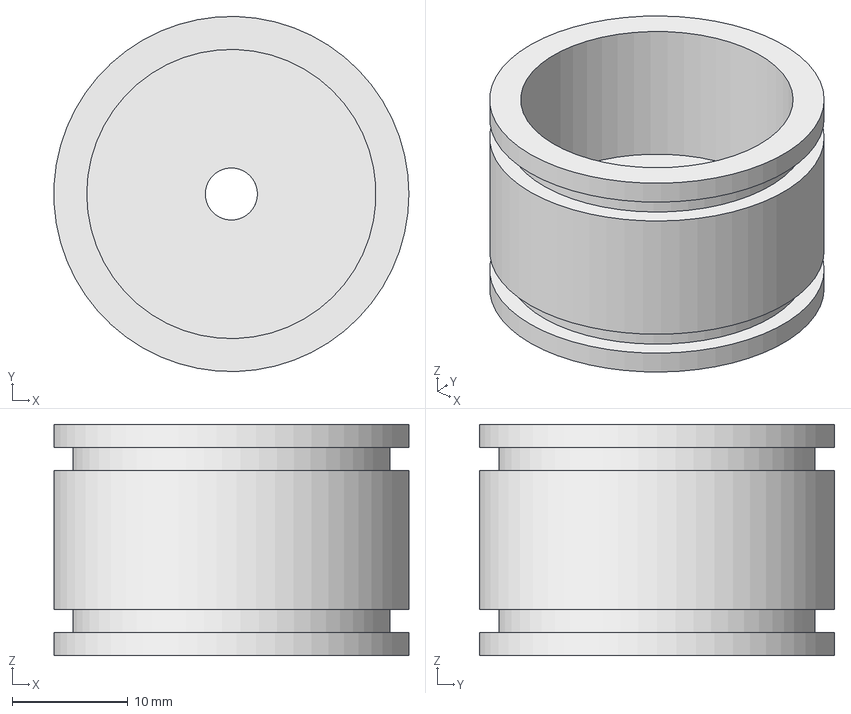
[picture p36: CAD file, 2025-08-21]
robot-info/3D Designs/Steering/FreecadFiles/Wheel.FCStd
30.7 x 30.7 x 20.0 mm

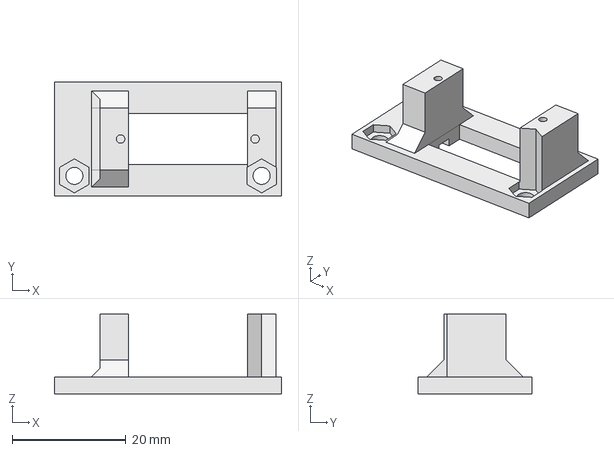
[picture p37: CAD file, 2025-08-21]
robot-info/3D Designs/Supports/FreecadFiles/ServoSupport.FCStd
40.0 x 20.0 x 14.1 mm

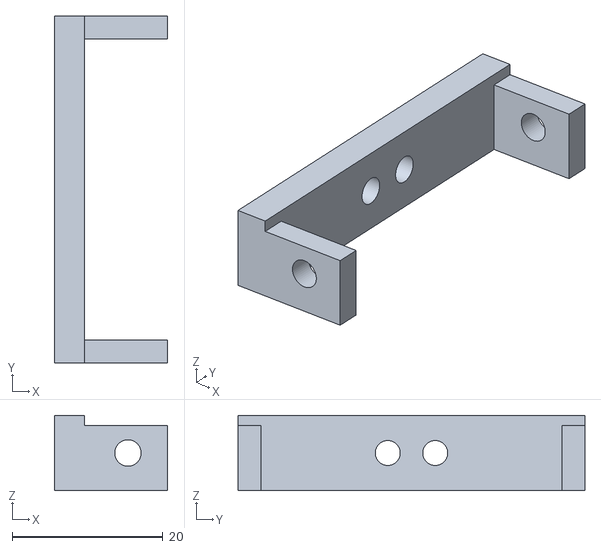
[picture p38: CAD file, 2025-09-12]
robot-info/3D Designs/Supports/ServoCameraSupport.stl
15.0 x 46.0 x 10.0

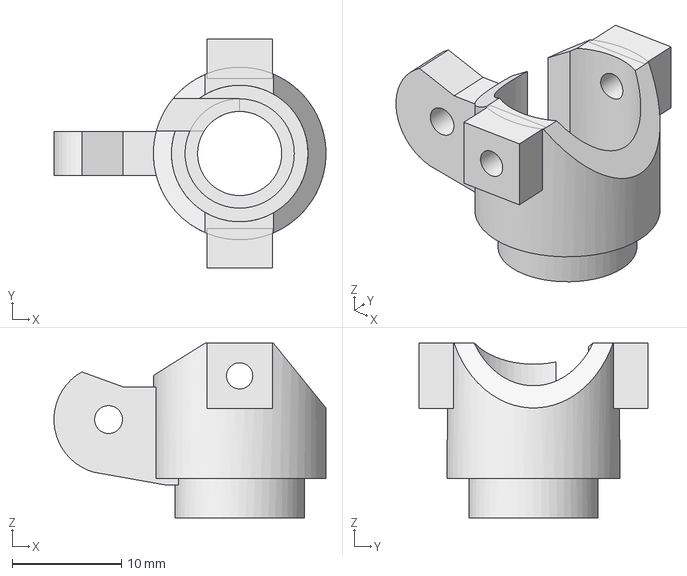
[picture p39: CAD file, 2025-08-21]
robot-info/3D Designs/Steering/FreecadFiles/WheelHook.FCStd
24.9 x 21.0 x 16.0 mm

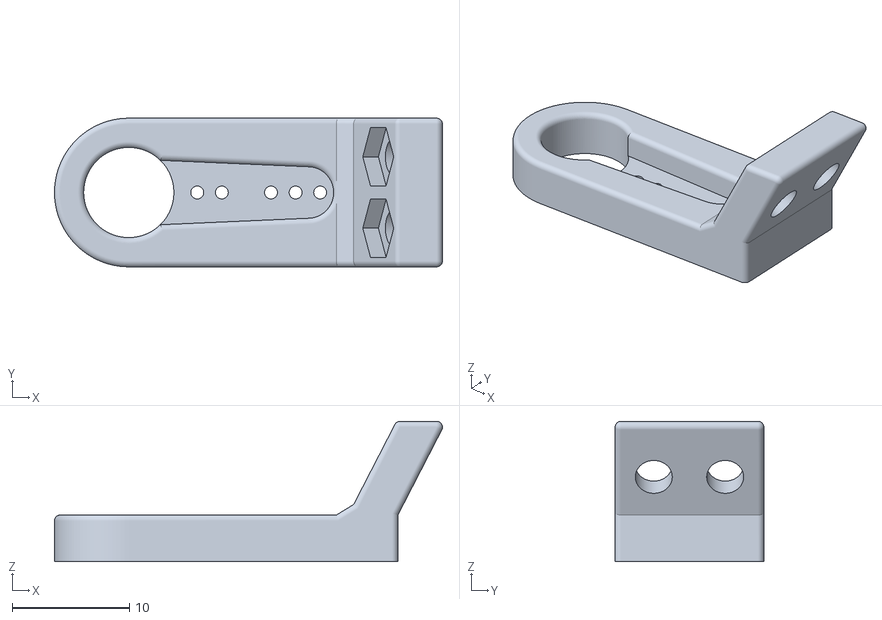
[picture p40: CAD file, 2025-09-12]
robot-info/3D Designs/Supports/CameraAndServo.stl
33.2 x 12.7 x 12.0

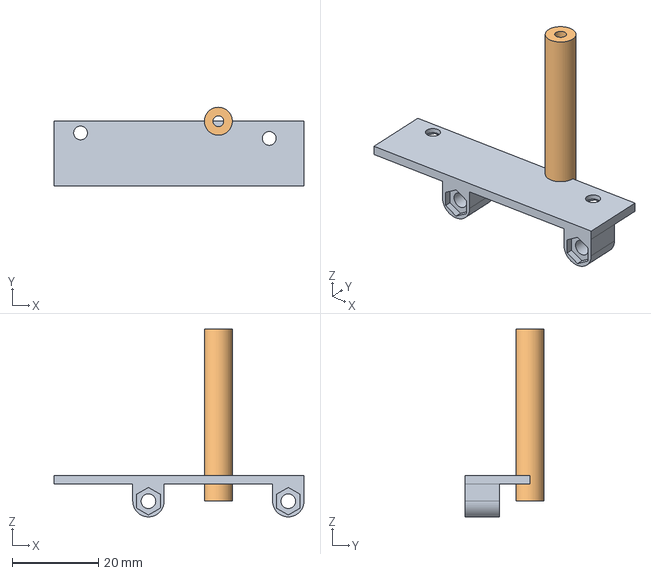
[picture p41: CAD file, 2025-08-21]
robot-info/3D Designs/Supports/FreecadFiles/PcbSupports.FCStd
58.1 x 18.2 x 43.7 mm
Trasero
Delantero

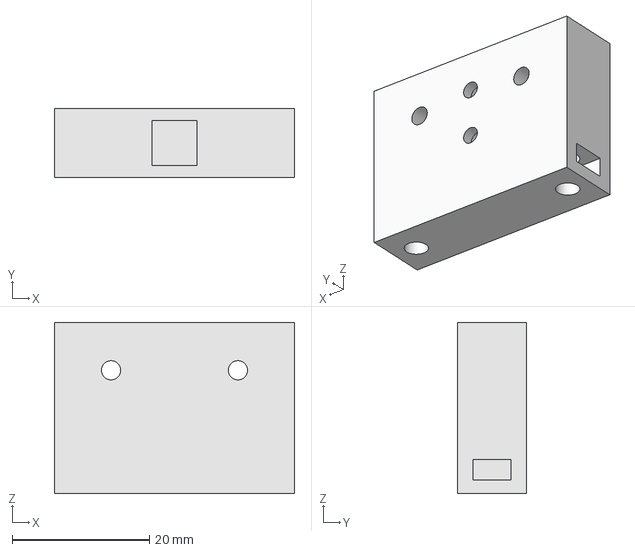
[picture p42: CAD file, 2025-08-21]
robot-info/3D Designs/Supports/FreecadFiles/CameraSupports.FCStd
35.0 x 10.0 x 25.0 mm

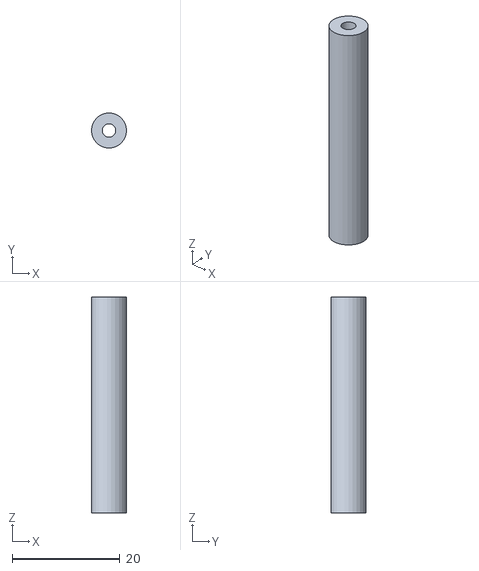
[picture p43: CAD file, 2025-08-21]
robot-info/3D Designs/Supports/PcbSupport-Front.stl
6.50 x 6.45 x 40.0

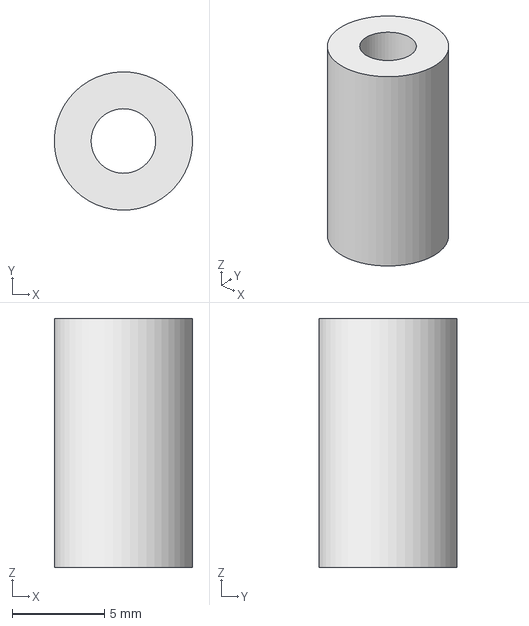
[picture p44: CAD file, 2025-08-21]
robot-info/3D Designs/Supports/FreecadFiles/LidarSupports.FCStd
7.49 x 7.50 x 13.5 mm

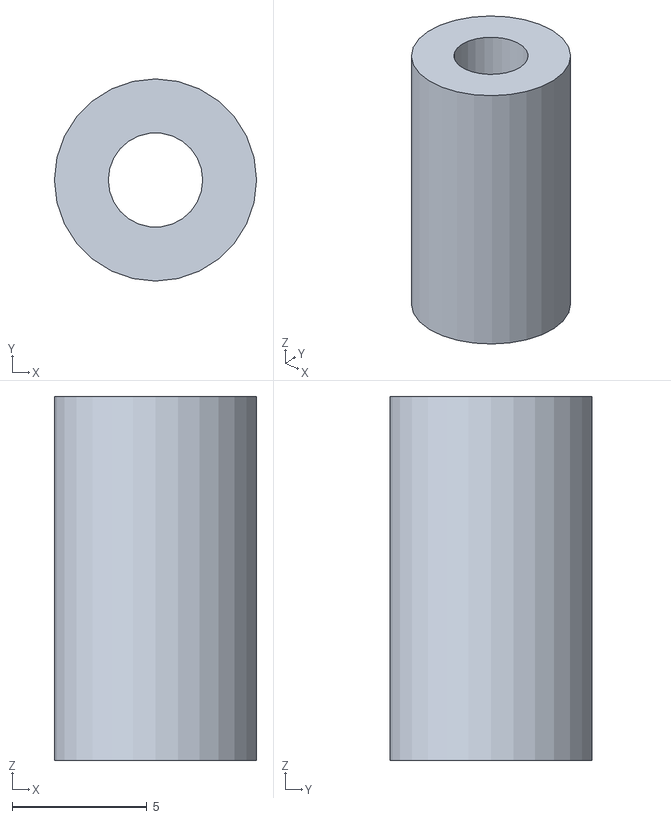
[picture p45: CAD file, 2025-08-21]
robot-info/3D Designs/Supports/LidarSupport-Back.stl
7.50 x 7.50 x 13.5

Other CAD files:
robot-info/3D Designs/Supports/FreecadFiles/Camara+Servo.FCStd
robot-info/3D Designs/Supports/FreecadFiles/SoportePCBatras1.FCStd
robot-info/3D Designs/Supports/CameraSupport.stl
robot-info/3D Designs/Supports/FreecadFiles/EncoderSupports.FCStd
robot-info/3D Designs/Steering/ServoArm.stl
robot-info/3D Designs/Steering/SteeringArm.stl
robot-info/3D Designs/Steering/Wheel.stl
robot-info/3D Designs/Steering/WheelHook.stl
robot-info/3D Designs/Supports/CameraSupport-Base.stl
robot-info/3D Designs/Supports/EncoderSupport-Axis.stl
robot-info/3D Designs/Supports/EncoderSupport-Base.stl
robot-info/3D Designs/Supports/LidarSupport-Front.stl
robot-info/3D Designs/Supports/PCB Screw Spacer.stl
robot-info/3D Designs/Supports/PcbSupport-Back.stl
robot-info/3D Designs/Supports/ServoSupport.stl

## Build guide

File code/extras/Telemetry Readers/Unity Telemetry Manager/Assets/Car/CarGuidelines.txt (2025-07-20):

In the Car folder you'll find a few ready-made Car prefabs, which are used in the Car sample scenes. These prefabs demonstrate how you can use the Car scripts we've included, including some AI-controlled variants which are able to drive directly towards a specified target, or follow a waypoint-based route.

The scripts included have been designed to be modular in nature, so that the extra features of a particular car can be set up (such as brake lights, engine sound, and skid trails).

The simplest way to get started setting up your own car is to use our "CarPrefabEmpty", and to follow these steps:

1) Start with a suitable scene. There ought to be enough flat ground to drive around on.

2) Place the "CarPrefabEmpty" in the scene.

3) Place your 3d model into the scene, as a child of the "CarPrefabEmpty" GameObject. Notice that your car model should be at the same level as the "WheelHub" objects that were already present.

4) Make sure your car's position in the inspector is set to 0,0,0. This will ensure your car's position is aligned with the Empty Prefab's position.

5) Expand the hierarchy of your car model in the hierarchy so that the wheel models of your car are visible.

6) Select each "WheelHub" in turn, and drag the corresponding wheel model from your car into the "Wheel Model" slot of the Wheel component on the WheelHub GameObject. Then click the "Align to assigned wheel model". If your car has four wheels, you'll need to do this step four times, once for each wheel. 

7) Hit play, and try driving your car!

You'll probably want to add a camera rig so that the camera follows the car as it drives off. See the Camera Rig guidelines for instructions on how to do that.

The Car script exposes a number of properties which determine the power, maximum speed, and handling of the car, however ultimately the script is designed to provide a fun arcade game-like feel rather than attempting to be a realistic simulation of car handling. The gears and revs values are purely cosmetic, and are calculated retrospectively - they can be used by the engine sound component or GUI to display revs and gear.

For more detail about each setting, see the comments in the script.

The CarUserControl script takes input from the "CrossPlatformInput" class included in the sample assets, however if you're not targeting mobile or prefer to use a different system to read input, you can simply use unity's built in Input class in place of CrossPlatformInput. For more information, see the Cross Platform Input guidelines.

The sample scenes provided work on standalone builds and also include cross platform touch and tilt controls which are set up and ready to publish to mobile. 

The CarAIControl component can be added instead of the CarUserControl component, allowing the car to be AI controlled. You can set it up to either head towards a specified target, or (by using the WaypointProgressTracker) follow a waypoint-defined route. See the WaypointCircuit guidelines for instructions.

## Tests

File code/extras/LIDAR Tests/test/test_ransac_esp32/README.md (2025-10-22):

This folder contains code to test the RANSAC algorithm on the ESP32, to do efficiency, speed and resoursce consume.

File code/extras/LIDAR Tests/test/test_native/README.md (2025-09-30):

This folder is used to make tests in the native enviroment, which is c++. This is to avoid flashing the ESP32 when trying to test logic and algorithms.
test_ransac tests the ransac algorithm given a data set.

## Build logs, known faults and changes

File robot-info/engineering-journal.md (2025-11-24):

# Engineering journal
In this journal we expose the process of the engineering of our robot.
The project starts in 2023, the last time our team competed in the WRO. From that car we have set the base for our current version.

# 2025

## June 26th - Initial commit and team constitution
First meeting of the team. We dismantled the car for cleaning and checking the state of the pieces.
The repository was created and the first commit was done. The README was created and the LICENSE was uploaded.

## July 1st - Repo structured and car rebuilt
After cleaning the car, we placed every component as in 2023 except for the camera.
In 2023 we found several issues with the Pixy2 camera during the National Final, bringing our run to an end.
The brightness of the camera could not be brought down from the maximum, hence disabling the car from distiniguishing any color from white.
This year, we have replaced the Pixy 2 for a HUSKY Lens, hoping for a better performance.
The HUSKY Lens, as well as the Pixy, has colour detection built-in to the camera. This allows an easier handling of the recognition task, since we only use the camera to detect the colour of the traffic lights.
We created folders to organise the GitHub repository, and uploaded a pinout for the new camera.
Finally, we designed and uploaded a screw spacer for the PCB, in order to prevent the PCB from being damaged by the screws.

## July 2nd - Update of the camera pinout
After a bit of research, we found out that the ESP32 microcontroller can take any two GPIOs as I2C ports.
This enables us to reuse the connections from 2023. The Pixy 2 supports SPI, contrarily to the HUSKY, but we may use the previous pins and set them up as I2C trough software.
The updated pinout was uploaded.

## July 3rd - ESP32 Master and Slave created
We created two Platform IO projects, one with the code for the ESP32 Master and another for the Slave.
We added code from the 2023 repo, which we will further correct and develop.

## July 7th - Phase 1 started
Today we started working on the Phase 1 of the challenge
We setup the Husky in the Slave to avoid the port being missused.
The telemetry was shortened in the Phase 1 so that we don't have to send the blocks detected, as it is not needed.
The README file of the code was drafted.

## July 10th - Reset problem handling
Today we encountered the first big problem. The car suddenly reboots during the laps. In 2023 this scarcely happened, but now it occurs almost every time we run the car.
In order to debug, we sent the error message of both ESP32 Master's cores via Telemetry.
On a first attempt to solve this issue we update a watchdog timer at the beggining the Lidar Task.
Attempt failed, the car kept rebooting with the same error messages.

## July 15th - Lidar work
On another, unsuccessful attempt of solving the reset issue, we disabled the watchdog timer of the core dedicated to the LIDAR.
The Lidar seems to take too long measuring distances to decide the turn sense, so we modify the readDistance function, which still doesn't work as wanted.
For debugging purposes, we store the distances to the right and to the left of the robot, to send them trough telemetry.

## July 17th - Simple camera code and corrections to the master
Simple code added to the ESP32 Slave to measure colour blocks with the HUSKY and send them to the Master.
We noticed a deviation of the car on start, due to the servo's 0 angle not being properly adjusted. We update the servo MIN and MAX in our CServo library to deal with it
We sent the reset reason of the Slave's cores to the master, whcih then sends it rough telemetry, trying to find out the reason of the rebooting of the car.
For quicker launches when testing the car, we created the PRACTICE_MODE define, which starts the car without expenting a button press when on true.
To check the conversion between encoder updates and milimeters, we created a test state "Prueba", which moves the car 3 "car" meters to calculate the quotient.
We further worked on the decideTurn and the readDistance functions, since they were still run to slow.

## July 19th - Phase 1 running
ReadDistance fucntion was finally working, after accounting for various measures and fixing a bug where the index of the array was set negative.
The reset error was finally explained and solved. There was a voltage cutoff due to the 3.3v power supply having too much current demand. It was solved by putting the ESP32 and the camera in different circuits. As a future task it would be better to design a new PCB.
The code folder was divided in two sub-folders, official- for the code that we wil use during the competition-, and extras.

## July 20th - Telemetry creation
ESP32 Telemtry was created to upload to the ESP32 Beetle which handles the telemetry. It receives bytes from the teleSerial port and sends them trough udp packets to a computer, specified by its IP.
Telemetry receivers were created to receive, decode and process the telemetry data sent by the ESP32 Master trough different udp packets.

## July 25th - Obstacle challenge code
The ESP32 Master Obstacles project was created to handle the obstacle challenge. It uses the same algorithm as the ESP Master, using switches for the checkTurn and Turn functions. The colour blocks are detected and change the objective position of each lane.
The code was imported from the 2023 repository.

## July 29th - Final Open Challenge corrections
The distances array from the lidar was duplicated before reading the distances so that writing and reading don't clash, since they occur in different cores. Also older measurements were accepted. Now decideTurn gets the turn sense quicker yet reliably, enabling us quicker completion times.

## July 30th - Camera tests
We created a Camera Testing project to test the code for the camera and colour block handling separetly from the main program.
The tested code was added to the ESP32 Slave, which will operate the camera in the main program.
From all the blocks detected, the heighest block is passed to the ESP Master, which will use this information to move the car.

## August 18th & 21st Documentation update
The repo README was sketched and the licenses were uploaded to the main license file for easier access.
We uploaded the STL and FreeCAD of the 3D models for the 3D printer, the parts being: steering and support components, wheels, sensor supports and PCB spacers. Included a README describing the folder structure and purpose of the models.

## August 22nd Update after holidays
Today's changes were mostly to get everything prepared before continuing to make changes. Changes were put up to date and some things were reorganised.
Telemetry was moved from official to extras for organisation purposes. The copy of ESP32 Telemetry, Telemetria 2.1 was removed since its changes were not relevant.
The code for the ESP32 Masters was syncronised. The updated LIDAR code of the Open Challenge was added to the Obstacle Challenge. The 2nd rounds speed system - based on defines for easier configuration - was implemented in the 1st round.
Innecesary states were removed; added track constants and the ENABLE_TELEMETRY define was added to the Open Challenge; practice mode was added to the phase 2 code.
Telemetry was unified, distance90 and distance270 were added to phase 2.
Finally, an problem with the transition from state e::Inicio to e::Recto, in which if the turnSense was decided too soon, e::Recto would never be reached.

## August 24th Camera block selection logic
We continued working on the Camera Testing project to work on the camera code. We aim for a better detection of the colour blocks by filtering the colour blocks depending on their width, height and the ratio of both. Since the blocks are rectangular prisms, we aim to detect an upward rectangle, such that the height/width ratio is greater than 1.
Some improvement to the telemetry has been made, spliting the camera data into another packet so that it only gets sent when there is new data. Additionally the age of the lidar measurements has been sent.

## August 26th Small Slave camera changes
Initialised the Husky to the Color Detection Algorithm by default, checked the conexion state and requested blocks before calling our filter function.
Added the decodification of the camera data to the receiver. Sent arrayBlocks through telemetry for an easier check of the colour blocks detected. This way we could check the filter algorithm better. Finally, for an easier debug, we have sent the millis as a packet timestamp.
We have added a header to each source file of our official projects, which refers to our repository and indicates the license associated with the file.

## September 1st README updates
We have further written the README file to better document our project. Images were added for an easier explanation of the robot.

## September 2nd Exiting the parking
Now that we have sorted the colour block detection we deal with the new feature introduced this year, parking.
We created a new project in extras to tackle the parking slot start and parking. We first intend to solve the start from the slot to test our car's steering on the slot.
Starting on the parking slot, we have decided that our robot should measure the distance to both side walls, whichever is greater shows the side to which we should turn to exit the slot. It turns out that we can use this information to decide the sense of turn and to set the X positon from start. On the other hand, now we cannot measure the Y distance from start since this distance is blocked by the slot walls.
Since the parking slot prevents traffic lights to be placed on the exterior of the 1st lane, we have moved inwards the exterior path of the car on the lane, preventing collisions with the parking slot.
We have deactivated the function that made the car turn around on the final lap. We have also incremented the speed increment to the 6th turn, but this doesn't seem to work.

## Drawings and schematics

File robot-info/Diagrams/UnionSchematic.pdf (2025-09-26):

## Steering

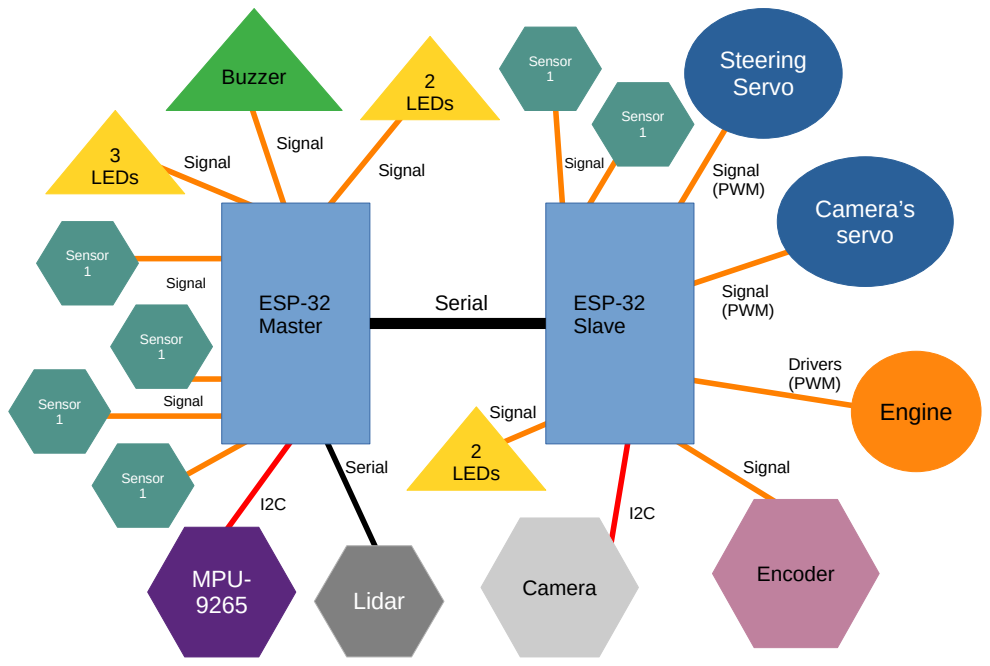
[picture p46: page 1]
ESP-32; Serial; Master; ESP-32 Slave; MPU-; Lidar; Camera; Encoder; Sensor 1; Engine; Camera’s servo; Servo Buzzer; LEDs; 2 LEDs; 3 LEDs; Signal; Drivers (PWM); Signal (PWM)

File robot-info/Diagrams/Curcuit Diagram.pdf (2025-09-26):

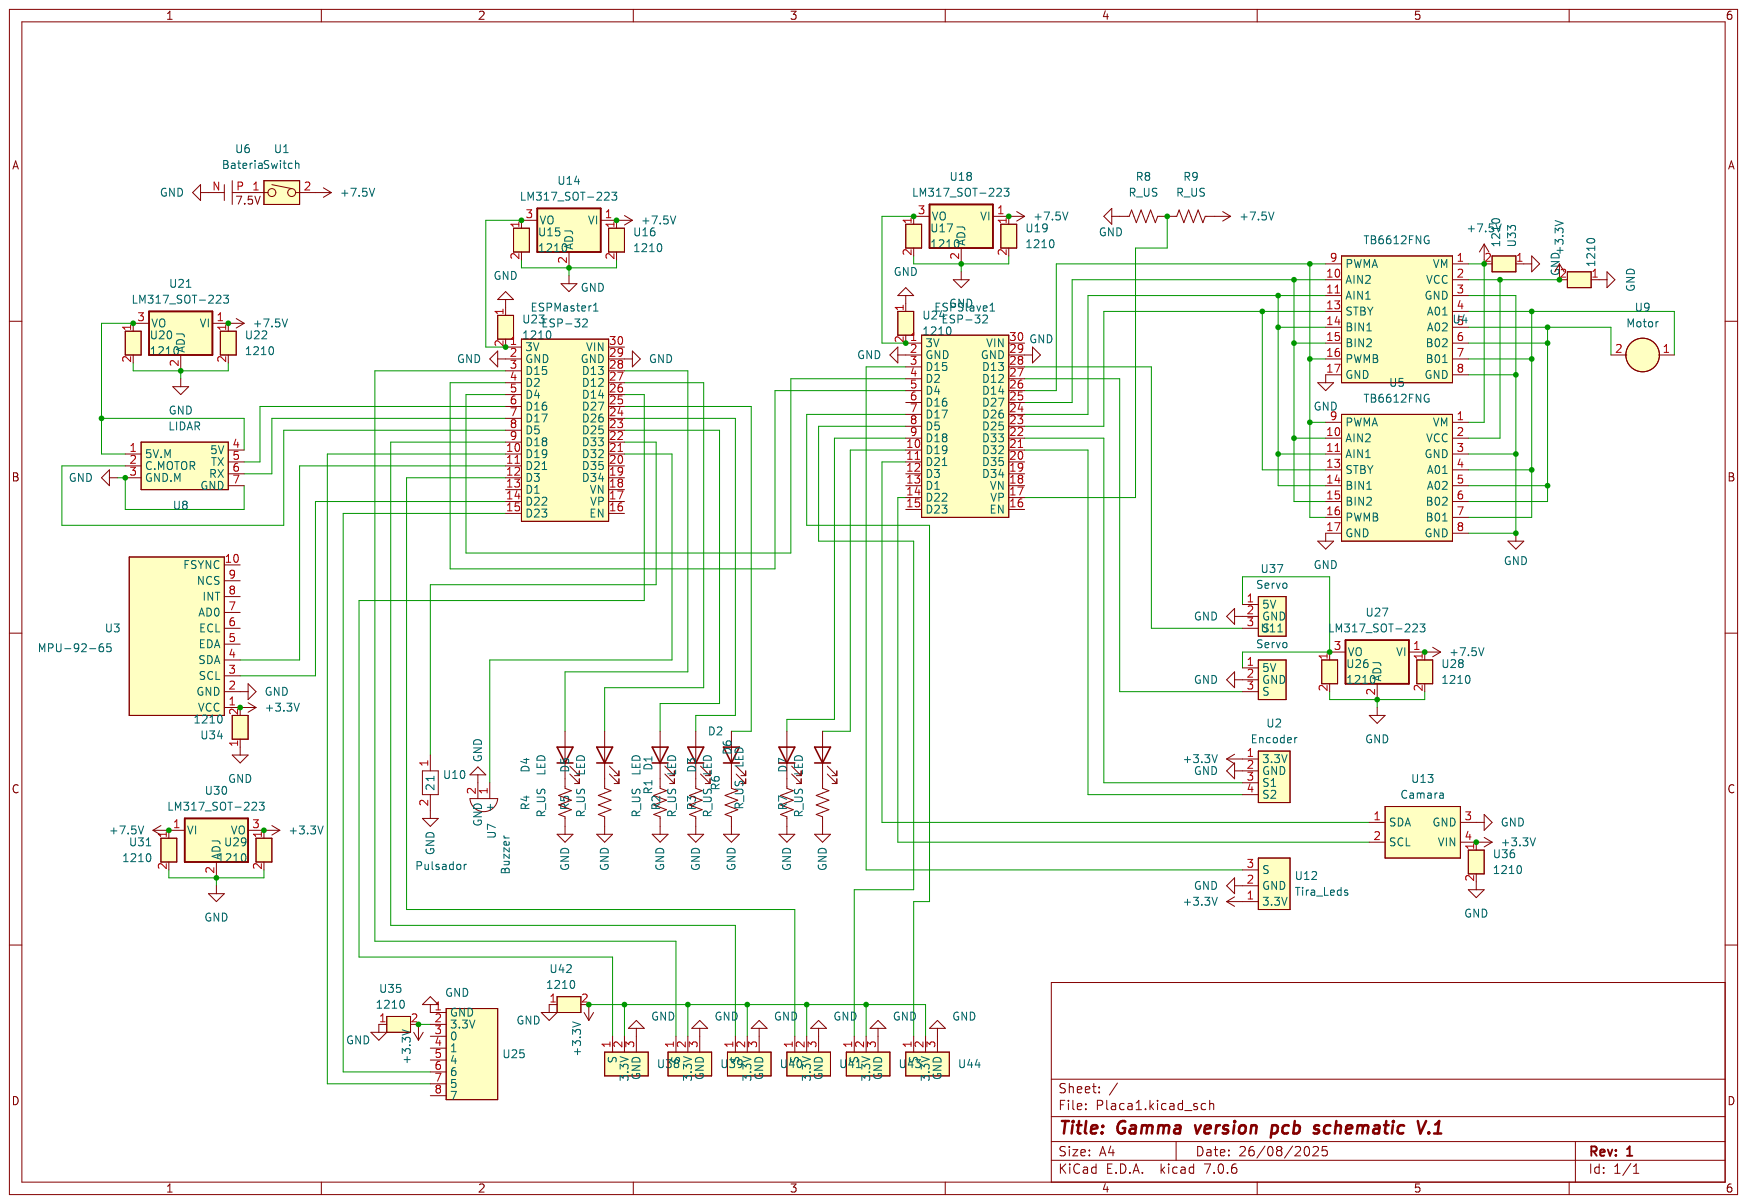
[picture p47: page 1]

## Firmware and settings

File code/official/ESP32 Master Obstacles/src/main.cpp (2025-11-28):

/***************************************************
 * 
 * THE MAIN REPOSITORY CAN BE FOUND AT https://github.com/qu4Vix/WRO-GammaVersion-2025
 * 
 * This code is under a GPL-3.0 license. More information can be found in the License file
 * in the repository.
 * 
****************************************************/

/***************************************************
 * 
 * This is the code for the "Main" ESP32 of our robot, which it is responsible for controlling
 * some sensors and to make all the decisions.
 * 
 * THIS VERSION OF THE ESP32 MASTER CODE IS ONLY FOR THE OBSTACLE CHALLENGE
 * For the Open Challenge use "ESP32 MASTER"
 *  
****************************************************/

#include <Arduino.h>
#include <AdvancedMPU.h>
#include <RPLidar.h>
//#include "credentials.h"
#include "pinAssignments.h"

#include <rom/rtc.h>
#include <esp_task_wdt.h>

// Practice mode (Button desabled) for easy launches while testing
#define PRACTICE_MODE false

// Enables wifi functions when true
#define ENABLE_WIFI false
#define ENABLE_TELEMETRY false

#define PARKING_LANE_DISTANCE 370

#define ROTATING_SPEED_LIDAR 200

#define TURNS_TO_UPDATE 15

/*#if ENABLE_WIFI == true
#include <OTAUpdate.h>
#include <Telemetry.h>

IPAddress receiversIP(192, 168, 0, 102);
uint16_t receiversPort = 4210;
uint16_t udpPort = 1234;
uint16_t otaPort = 80;

Updater miota(otaPort);
TelemetryManager telemetry(receiversIP, receiversPort);
#endif
*/
// Speeds
#define StartSpeed 2
#define CruisiereSpeed 10
#define NormalSpeed 4

/*
 *  Speed infromation
 *  Minimum speed: 2
 *  Safe speed for recognition: 3
 *  Safe speeds for cruisiere: 5,6
 *  Risky speed: 7
 *
 * 
 */

// Servo and direction variables

#define servoKP 2.5
#define servoKD 0
int prev_setAngle;
int actual_directionError;
int prev_directionError;
float objectiveDirection;

// battery level variable
uint8_t bateria;

// camera signatures

#define GreenSignature 1
#define RedSignature 2

bool firma1Detectada = false;
uint8_t firma1X = 18;
uint8_t firma1Y = 19;
bool firma2Detectada = false;
uint8_t firma2X = 20;
uint8_t firma2Y = 21;

// conversion between mm and encoder counts
#define MMperEncoder 1.543

// List of possible states for the car
enum e {
  Inicio,
  Recto,
  Final,
  Arrancar,
  Reposicionar,
  Reinicio, // Not necessary -------------------------------------------------------------------------------------------------
  Posicionamiento,
  EntradaFase1,
  EntradaFase2,
  EntradaFase3,
  EntradaFase4,
  Aparcar1,
  Aparcar2,
  Aparcar3,
  Aparcar35,
  Aparcar4,
  Esperar,
  Prueba,
  Aparcar5,
  Aparcar6
};
uint8_t estado = e::Arrancar;

// track constants

// size of the map (mm)
#define mapSize 3000
// width of the lanes
#define trackWidth 1000
// coordinate of the central lane (mm)
#define trackCenter 500
// coordinate of the lateral lane (mm)
#define trackLateral 300
// distance to path on which the car should try to turn (mm)
#define turnOffset 300

// Car constants
#define carWidth 150
#define carLength 240
#define lidarToImu 150

// journey variables

// Variable vueltas
byte vueltas = 0;




// number of turns
uint8_t giros = 0;
uint8_t totalGiros = 0;
// section in which the car is
uint8_t tramo = 1;
// turnSense = 1 when ANTICLOCKWISE; turnSense = -1 when CLOCKWISE
int8_t turnSense = 0;
// whether you have to turn clockwise or not
bool turnClockWise;
// whether we are moving forwards (+1) or backwards (-1), in order to account for corrections in the PID. We initialize it at 0 (not moving)
int8_t motionDirection = 0;
bool isRecognizing = true;
bool isParking = false;
bool isMoveCamera = true; //GOD HELP ME

// encoder variables

int32_t encoderMeasurement;
int32_t prev_encoderMeasurement;

double prev_angleMagico;

// lidar measurement variables

uint16_t distances[360];
static uint32_t distancesMillis[360];
uint16_t distancia0;
uint16_t distancia90;
uint16_t distancia270;

//Constrain variable de la posición, para que se abra un poco...
#define constrainNormal 90
#define constrainAbrir 120

int ConstrainVariable = constrainNormal;

// car position on the map (origin at the bottom-left corner)

// x position of the car (increases to the right)
double xPosition = 0;
// y position of the car (increases upwards)
double yPosition = 0;

#define posYmagica 1500 // value of initialization of the variable yPosition so that program starts normally, even though the yPos is properly obtained in state e::Volver

double startXposition;
double marcaPos;
unsigned long marcaMillis;
byte marcaEstado;

// position PID controller variables

#define positionKP 0.4  // different from phase 1 for some reason --------------------------------------------------------------------
#define positionKD 4
#define positonKPmagico 90
#define positionKPaparcar 3.5
#define positionKDaparcar 12.5 //Ajustar para que haga las maniobras bien, y todo el lio...
float KPActual = positonKPmagico;
float KDActual = positionKD;
int objectivePosition = 0;
float positionError;
float prev_positionError;
bool fixXposition = true;
bool fixInverted = true;
bool pidEnabled = true;

uint32_t MIT;
bool lidarEnabled = true;

// trajectory management variables

// not used
uint16_t tramos[2][8] = {
  {500,500,2500,2500,2500,2500,500,500},
  {mapSize - trackCenter, mapSize - trackCenter, mapSize - trackCenter, mapSize - trackCenter, trackCenter, trackCenter, trackCenter, trackCenter}
};

// array to save the blocks detected. the odd indices save the first block of a section while the even save the second or third
uint8_t arrayBloques[8] = {0, 0, 0, 0, 0, 0, 0, 0};
// 
const uint16_t blockPaths[2][4][3] =
{
  { // anticlockwise
    //Center, left, right
    {2500, mapSize - trackCenter - trackLateral, mapSize - 380}, // first lane
    {2500, mapSize - trackCenter - trackLateral, mapSize - trackCenter + trackLateral}, // second lane
    {500, trackCenter + trackLateral, trackCenter - trackLateral}, // third lane
    {500, trackCenter + trackLateral, trackCenter - trackLateral} // fourth lane
  },
  { // clockwise
    // Center, left, right
    {500, 380, trackCenter + trackLateral}, // first lane
    {2500, mapSize - trackCenter + trackLateral, mapSize - trackCenter - trackLateral}, // second lane
    {2500, mapSize - trackCenter + trackLateral, mapSize - trackCenter - trackLateral}, // third lane
    {500, trackCenter - trackLateral, trackCenter + trackLateral} // fourth lane
  }
};

const uint16_t blockPositions[2][4][3] = 
{
  { // Anticlockwise
    // First, second, third block
    {950, 1400, 1900}, // first lane
    {2100, 1600, 1050}, // second lane
    {2100, 1600, 1050}, // third lane
    {950, 1400, 1900} // fourth lane
  },
  { // Clockwise
    // First, second, third block
    {950, 1400, 1900}, // first lane
    {950, 1400, 1900}, // second lane
    {2100, 1600, 1050}, // third lane
    {2100, 1600, 1050} // fourth lane
  }
};
uint8_t lastBlock;
bool senseDirectionChanged = false;
bool bloqueEnMedio = false;
uint16_t parkingY;

// object declarations

MPU mimpu;
HardwareSerial lidarSerial(2);
RPLidar lidar;
HardwareSerial commSerial(1);
TaskHandle_t TaskLidar;
HardwareSerial teleSerial(0);
TaskHandle_t TaskIMU;

// calculate the error in the direction
int directionError(int bearing, int target);
float directionError(double bearing, int target);

// esp32 intercommunication functions

// set the car's speed
void setSpeed(int speed);
// set the angle of the servo
void setSteering(int angle);
// receive data from the serial
void receiveData();
// turn a led on depending on the tension received
void manageTension(uint8_t tension);

// LIDAR management variables

// get the index in the distances array for an angle given
uint16_t getIndex(float angle);
// Angle from 0 to 359
uint16_t readDistance(uint16_t angle);
// Create code for the task which manages the LIDAR
void LidarTaskCode(void * pvParameters);

// send a piece of data to the telemetry esp32
void enviarDato(byte* pointer, int8_t size);

// functions for the management of the car's position

void iteratePosition(void * pvParameters);
void iteratePositionPID();  // invoke an iteration of the pid controller for the position
void turn();            // turn
void setXcoord(uint16_t i);   // set the coordinate x axis
void setYcoord(uint16_t f);   // set the coordinate y axis
void decideTurn();  // detect the sense of turn
void checkTurn();   // check wether you have to turn or not

void changeLane(uint8_t _tramo);
bool setCoordTramo(uint8_t tramo, uint16_t leftCoord, uint16_t rightCoord);
void correctLane(uint8_t _tramo);
void changeDrivingDirection();

void moveCamera(int8_t angle);
void autoMoveCamera();
void enableCamera();
void updatePosition();

void saveParkingPosition();

void teleEnviar();

void pitiditos(int num){
  while(num > 0){
    digitalWrite(pinBuzzer, HIGH);
    delay(50);
    digitalWrite(pinBuzzer,LOW);
    delay(50);
    num--;
  }
}

void estadoEsperar(byte estadoObjetivo, uint16_t delay) {
  //pitiditos(1);
  marcaMillis = millis() + delay;
  marcaEstado = estadoObjetivo;
  estado = e::Esperar;
}

void setup() {
  // put your setup code here, to run once:
  setPinModes();
  //pitiditos(1);
  #if ENABLE_TELEMETRY == true
  // begin telemetry serial
  teleSerial.begin(1000000, SERIAL_8N1, telemetriaRX, telemetriaTX);
  #else
  // begin serial
  //teleSerial.begin(1000000, SERIAL_8N1, telemetriaRX, telemetriaTX);
  Serial.begin(1000000);
  #endif
  // begin esp32 intercommunication serial
  commSerial.begin(1000000, SERIAL_8N1, pinRX, pinTX);

  // set all the pin modes
  
  mimpu.SetDebugLedPin(pinLED_rojo);
/*
  #if ENABLE_WIFI == true
    miota.WiFiInit();
    miota.SetStaticIP(250);
    miota.OTAInit();

    telemetry.StartUDP(udpPort);
  #endif
*/
  // configure the mpu
  mimpu.BeginWire(pinMPU_SDA, pinMPU_SCL, 400000);
  mimpu.Setup();
  delay(20000);
  mimpu.WorkOffset();
  //pitiditos(2);
  // begin the lidar
  lidar.begin(lidarSerial);
  rplidar_response_device_info_t info;
  while (!IS_OK(lidar.getDeviceInfo(info, 100))) delay(500);
  rplidar_response_device_health_t health;
  lidar.getHealth(health);
  //Serial.println("info: " + String(health.status) +", " + String(health.error_code));
  // detected...
  lidar.startScan();
  //pitiditos(3);
  //esp_task_wdt_deinit();
  // Asign lidar Task to core 0
  xTaskCreatePinnedToCore(
    LidarTaskCode,
    "LidarTask",
    100000,
    NULL,
    10,
    &TaskLidar,
    0);/*
  xTaskCreatePinnedToCore(
    iteratePosition,
    "ImuTask",
    100000,
    NULL,
    10,
    &TaskIMU,
    0);*/
  delay(500);
  //pitiditos(4);
  // start lidar's motor rotating at max allowed speed
  analogWrite(pinLIDAR_motor, ROTATING_SPEED_LIDAR);
  delay(500);

  // initialize y position and wait until the turn sense is decided and the x coordinate is calculated
  digitalWrite(pinLED_rojo, HIGH);
  yPosition = posYmagica;
  while (turnSense==0)
  {
    decideTurn();
  }
  startXposition = xPosition;
  digitalWrite(pinLED_rojo, LOW);
  
  // handle this in case the car has to turn around in final lap --------------------------------------------------------------
  //if (yPosition >= 1500) bloqueEnMedio = true;
  
  #if PRACTICE_MODE == true
  // Receive data from the intercommunication serial
  while (commSerial.available())
  {
    receiveData();
  }
  #else
  // Waits until the start button is pressed while reading from the intercommunication serial
  digitalWrite(pinLED_amarillo, HIGH);
  while (digitalRead(pinBoton)) {
    while (commSerial.available())
    {
      receiveData();
    }
  }
  digitalWrite(pinLED_amarillo, LOW);
  #endif
  prev_encoderMeasurement = encoderMeasurement;
  prev_angleMagico = mimpu.GetAngle();
  delay(500);

  // move camera away from parking lot
  autoMoveCamera();
  firma1Detectada=firma2Detectada=0;
  // set default first lane path to the inner one in order for the camera to look away from the block
  if (turnClockWise) arrayBloques[0] = arrayBloques[1] = GreenSignature;
  else arrayBloques[0] = arrayBloques[1] = RedSignature;
  // set the objective position of the unparking and activate the PID
  objectivePosition = 2500-2000*turnClockWise;
  pidEnabled = true;
  // start driving (set a speed to the car and initialize the mpu) 
  mimpu.MeasureFirstMicros();


  digitalWrite(pinLED_batAmarillo, HIGH);

  setSpeed(StartSpeed);
}

void loop() {
  // put your main code here, to run repeatedly:

  // receive data from the intercommunication serial
  while (commSerial.available())
  {
    receiveData();
  }

  // update mpu's angle
  mimpu.UpdateAngle();

  // repeat position functions every 32ms
  static uint32_t prev_ms_position = millis();
  if (millis() >= prev_ms_position) {
    if (encoderMeasurement != prev_encoderMeasurement) {
      // calculate the increment in position and add it

      double angulomagico = mimpu.GetAngle();
      int32_t incrementoMagico = encoderMeasurement - prev_encoderMeasurement;
      double da = (angulomagico - prev_angleMagico) / incrementoMagico;

      /*double dy = (encoderMeasurement - prev_encoderMeasurement) * cos(mimpu.GetAngle() * (M_PI/180)) * MMperEncoder;
      double dx = (encoderMeasurement - prev_encoderMeasurement) * sin(mimpu.GetAngle() * (M_PI/180)) * MMperEncoder;*/

      double dy = 0;
      double dx = 0;
      for (int i = 1; i <= abs(incrementoMagico); i++)
      {
        dy = dy + motionDirection * cos((prev_angleMagico + da*i) * (M_PI/180)) * MMperEncoder;
        dx = dx + motionDirection * sin((prev_angleMagico + da*i) * (M_PI/180)) * MMperEncoder;
      }

      prev_encoderMeasurement = encoderMeasurement;
      prev_angleMagico = mimpu.GetAngle();
      xPosition -= dx; // x -> + derecha - izquierda
      yPosition += dy;

    }
    if (pidEnabled) {
      iteratePositionPID();
    }

    if (MIT < millis() - prev_ms_position) MIT = millis() - prev_ms_position;

    prev_ms_position = millis() + 32;
  }

  static uint32_t prev_Cam = millis();
  if (millis() >= prev_Cam) {
    if (isMoveCamera) {
      autoMoveCamera();
    }
    prev_Cam = millis() + 100;
  }

  #if ENABLE_TELEMETRY == true
  // send telemetry every 100ms
  static uint32_t prev_ms_tele = millis();
  if (millis() > prev_ms_tele + 500)
  {
    /*
    distancia0 = readDistance(0);
    distancia90 = readDistance(90);
    distancia270 = readDistance(270);*/

    /*FORMATO TELEMETRIA
    |inicioTX            |TipoPaquete|Datos|
      0xAA,0xAA,0xAA,0xAA,0x--,0x--...0x--
    */
   /*ENVIAMOS PAQUETE TIPO 4 DISTANCIAS*/
   /*
    for(int i = 0; i<4; i++){
      teleSerial.write(0xAA);
    }
    teleSerial.write(04);
    uint16_t zi=0;
    while (zi < 360)
    {
        teleSerial.write(distances[zi]>>8);
        teleSerial.write(distances[zi]&0x00ff);
        zi++;
    }
    //ENVIAMOS PAQUETE TIPO 3 CALIDAD MEDIDA/
    for(int i = 0; i<4; i++){   //Enviamos la cabecera de inicio de paquete
      teleSerial.write(0xAA);
    }
    teleSerial.write(03);
    uint16_t pi=0;
    while (pi < 360){
        teleSerial.write(distancesMillis[pi]);
        pi++;
    }
    */
    /*ENVIAMOS PAQUETE TIPO 5 INFORMACION GENERAL*/
    
    for(int i = 0; i<4; i++){   //Enviamos la cabecera de inicio de paquete
      teleSerial.write(0xAA);
    }
    teleSerial.write(byte(06));
    unsigned long time = MIT;  //--------Si, si, todo eso...
    long posXLong = long(xPosition);
    long posYLong = long(yPosition);
    long posXObjLong = long(objectivePosition);
    long posYObjLong = (turnSense==-1)?1:(turnSense==1)?2:0;
    long anguloLong = long(mimpu.GetAngle());
    long anguloObjLong = long(objectiveDirection);
    enviarDato((byte*)&time,sizeof(time));
    enviarDato((byte*)&posXLong,sizeof(posXLong));
    enviarDato((byte*)&posYLong,sizeof(posYLong));
    enviarDato((byte*)&posXObjLong,sizeof(posXObjLong));
    enviarDato((byte*)&posYObjLong,sizeof(posYObjLong));
    enviarDato((byte*)&encoderMeasurement,sizeof(encoderMeasurement));
    enviarDato((byte*)&estado,sizeof(estado));
    enviarDato((byte*)&bateria,sizeof(bateria));
    enviarDato((byte*)&anguloLong,sizeof(anguloLong));
    enviarDato((byte*)&anguloObjLong,sizeof(anguloObjLong));
    enviarDato((byte*)&tramo,sizeof(tramo));
    enviarDato((byte*)&distancia0,sizeof(distancia0));
    enviarDato((byte*)&distancia90,sizeof(distancia90));
    enviarDato((byte*)&distancia270,sizeof(distancia270));
    /*
    for(int i = 0; i<4; i++){   //Enviamos la cabecera de inicio de paquete
      teleSerial.write(0xAA);
    }
    teleSerial.write(byte(07));
    enviarDato((byte*)&firma1Detectada,sizeof(firma1Detectada));
    enviarDato((byte*)&firma1X,sizeof(firma1X));
    enviarDato((byte*)&firma1Y,sizeof(firma1Y));
    teleSerial.write(0x00);teleSerial.write(0x00);
    enviarDato((byte*)&firma2Detectada,sizeof(firma2Detectada));
    enviarDato((byte*)&firma2X,sizeof(firma2X));
    enviarDato((byte*)&firma2Y,sizeof(firma2Y));
    teleSerial.write(0x00);teleSerial.write(0x00);
    
    for(int i = 0; i<4; i++){   //Enviamos la cabecera de inicio de paquete
      teleSerial.write(0xAA);
    }
    teleSerial.write(byte(01));
    enviarDato((byte*)&arrayBloques,sizeof(arrayBloques));
    teleSerial.write(0x00);teleSerial.write(0x00);

    for(int i = 0; i<4; i++){   //Enviamos la cabecera de inicio de paquete
      teleSerial.write(0xAA);
    }
    teleSerial.write(byte(00));
    teleSerial.write("TG: ");
    teleSerial.write(totalGiros);*/
    
    prev_ms_tele = millis();
  }
  #endif

  // check turn every 50ms
  static uint32_t prev_ms_turn = millis();
  if (millis() > prev_ms_turn) {
    // No need to turn around in the final lap this year, so we will comment the function
    //if (totalGiros == 8) changeDrivingDirection();

    // Check whether we have to turn or steer to avoid color blocks
    if (!isParking) checkTurn();
    prev_ms_turn = millis() + 50;
  }

  // repeat direction pid iterations every 20ms
  static uint32_t prev_ms_direction = millis();
  if (millis() > prev_ms_direction) {
    if (pidEnabled) {
      actual_directionError = constrain(directionError(mimpu.GetAngle(), objectiveDirection), -127, 127);
      int _setAngle = servoKP * actual_directionError + servoKD * (actual_directionError - prev_directionError);
      if(_setAngle != prev_setAngle) {
        setSteering(_setAngle * motionDirection);
        prev_setAngle = _setAngle;
      }
      prev_directionError = actual_directionError;
      prev_ms_direction = millis() + 20;
    }
  }

  // state machine
  switch (estado)
  {
  case e::Inicio:
    //firma1Detectada = firma2Detectada = false; choose what to do with this line too --------------------------------------------------------
    //objectivePosition = xPosition; //decide what to do with this line ----------------------------------------------------------------------
    //vTaskSuspend(TaskLidar);
    //lidarEnabled = false;
    //analogWrite(pinLIDAR_motor, 0);
    estado = e::Recto;
    setSpeed(NormalSpeed);
  break;
  case e::Recto:
    if ((totalGiros == 12) && (tramo==1)) {
      estado = e::Posicionamiento;
    }
    if (totalGiros == 5) {
      setSpeed(CruisiereSpeed);
    }
  break;

  case e::Final:  // we probably want to be redirected to here after we finish the parking manouver ---------------------------------------------
    setSteering(0);
    analogWrite(pinLIDAR_motor, 0);

    if (yPosition >= 1200) {
      setSpeed(0);
    }
  break;

  case e::Arrancar:
    correctLane(1);
    //Ajustar el avance para que no se pase del bloque y tal...
    if (xPosition*turnSense <= startXposition*turnSense - 150)
    {
      setSpeed(0);
      delay(10);
      estadoEsperar(e::Reposicionar, 3000);
    }
  break;

  case e::Reposicionar:
    distancia0 = readDistance(0);
    if (distancia0 > 0)
    {
      setYcoord(distancia0);
      saveParkingPosition();
      KPActual = positionKP;
      estado = e::Inicio;
      //estadoEsperar(e::Inicio, 15000);
    }
  break;

  case e::Posicionamiento:
    //Usamos mejor sistema de posicionamiento para no depender de donde hemos puesto originalmente el robot (como pasaba antes)
    if (turnClockWise == true)
    {
      objectivePosition = PARKING_LANE_DISTANCE;
    }else{
      objectivePosition = 3000 - PARKING_LANE_DISTANCE;
    }
    //KPActual = positionKP;
    isParking = true;
    setSpeed(StartSpeed);
    estado = e::Aparcar1;
  break;

  case e::EntradaFase1:
    if (yPosition >= parkingY)
    {
      setSpeed(0);
      estadoEsperar(e::EntradaFase2, 500);
    }
  break;
  case e::EntradaFase2:
    KPActual = positionKPaparcar;
    KDActual = positionKDaparcar;
    setSpeed(-StartSpeed);
    objectivePosition = startXposition;
    estado = e::EntradaFase3;
  break;
  case e::EntradaFase3:
    if (yPosition <= 1650-500*turnClockWise)
    {
      KPActual = positionKP;
      KDActual = positionKD;
      setSpeed(0);
      /*
      delay(50);
      marcaPos = yPosition;
      setSpeed(StartSpeed); // probably not necessary if we stop on point -----------------------------------------------------------
      estado = e::EntradaFase4;*/
    }
  break;
  case e::EntradaFase4:
    if (yPosition >= marcaPos+50)
    {
      setSpeed(0);
    }
  break;
  /*
  maniobra alternativa
  parar a 1900
  marcha atras y girar tuedas a tope hasta que marque 90º (*turnSense)
  girar ruedas hacia el otro lado y volver hacia atras hasta que el angulo sea 0
  parar
  */
  
  case e::Aparcar1:
    if (yPosition >= 1360 + 620 - 620*turnClockWise)
    {
      setSpeed(0);
      pidEnabled = false;
      estadoEsperar(e::Aparcar2, 500);
    }
  break;

  case e::Aparcar2:
    setSteering(-90*turnSense);
    setSpeed(-StartSpeed);
    estado = e::Aparcar3;
  break;

  case e::Aparcar3:
    if ((mimpu.GetAngle()*turnSense - 90*totalGiros) >= 85) {
      setSpeed(0);
      estadoEsperar(e::Aparcar35, 200);
    }
  break;

  case e::Aparcar35:
    setSteering(90*turnSense);
    setSpeed(-StartSpeed);
    estado = e::Aparcar4;
  break;
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

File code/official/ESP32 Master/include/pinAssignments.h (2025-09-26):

// LED pins
#define pinLED_rojo 12
#define pinLED_verde 13

// Battery level LED pins
#define pinLED_batRojo 25
#define pinLED_batAmarillo 26
#define pinLED_batVerde 27

// buzzer
#define pinBuzzer 32

// LIDAR pins (UART2 + PWM)
#define pinLIDAR_TX 16
#define pinLIDAR_RX 17
#define pinLIDAR_motor 5

// MPU pins (I2C)
#define pinMPU_SDA 21
#define pinMPU_SCL 22

// Interchip Communication pins (UART)
#define pinTX 2
#define pinRX 4

// Button pin
#define pinBoton 33

// Telemetry serial pins
#define telemetriaTX 19
#define telemetriaRX 23

// Pin Modes
void setPinModes() {
    pinMode(pinBoton, INPUT_PULLUP);
    pinMode(pinLED_rojo, OUTPUT);
    pinMode(pinLED_verde, OUTPUT);
    pinMode(pinLED_batRojo, OUTPUT);
    pinMode(pinLED_batAmarillo, OUTPUT);
    pinMode(pinLED_batVerde, OUTPUT);
    pinMode(pinBuzzer, OUTPUT);
    pinMode(pinLIDAR_motor, OUTPUT);
}

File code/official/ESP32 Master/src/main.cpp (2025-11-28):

/***************************************************
 * 
 * THE MAIN REPOSITORY CAN BE FOUND AT https://github.com/qu4Vix/WRO-GammaVersion-2025
 * 
 * This code is under a GPL-3.0 license. More information can be found in the License file
 * in the repository.
 * 
****************************************************/

/***************************************************
 * 
 * This is the code for the "Main" ESP32 of our robot, which it is responsible for controlling
 * some sensors and to make all the decisions.
 * 
 * THIS VERSION OF THE ESP32 MASTER CODE IS ONLY FOR THE OPEN CHALLENGE
 * For the Obstacle Challenge use "ESP32 MASTER OBSTACLES"
 *  
****************************************************/



// ***** INCLUDING THE LIBRARIES *****

#include <Arduino.h>
#include <AdvancedMPU.h>
#include <RPLidar.h>
#include "pinAssignments.h"
#include <rom/rtc.h>
#include <esp_task_wdt.h>



// ***** DEFINES *****

// Practice mode (Button desabled) for easy launches while testing
#define PRACTICE_MODE false

// Enables wifi functions when true
#define ENABLE_WIFI false       // WIFI IS NOT USED ON THIS BOARD DURING THE MATCH, only for debug purpose

// This enables the transmission of telemetry used for debugging. In normal situations it is not needed to set this define to FALSE.
#define ENABLE_TELEMETRY false

// Speeds
#define StartSpeed 4
#define CruisiereSpeed 8
#define NormalSpeed 7

// Servo and direction variables
#define servoKP 2.5
#define servoKD 0

// Position PID controller variables
#define positionKP 0.35
#define positionKD 2.5



// ***** INITIALIZING VARIABLES, OBJECTS AND FUNCTIONS *****

// Direction related variables
int prev_setAngle;
int actual_directionError;
int prev_directionError;
float objectiveDirection;

// Battery level variable
uint8_t bateria;

// Conversion between mm and encoder counts
#define MMperEncoder 1.543

// List of possible states for the car
enum e {
  Inicio,
  Posicionar,
  Recto,
  Final,
  Esperar,
  Prueba
};
uint8_t estado = e::Inicio;

// Size of the map (mm)
#define mapSize 3000

// Journey variables
uint8_t giros = 0;
uint8_t tramo = 0; //empezamos en 1, ...
int8_t turnSense = 0;       // We don't know it at the beginning, 0->we don't know, 1->anti, -1->clockwise
int8_t motionDirection = 0; // The car doesn't move at the beginning

// Encoder variables
u_int32_t encoderMeasurement;
u_int32_t prev_encoderMeasurement;

double prev_angleMagico;

// Lidar measurement variables
uint16_t distances[360];
static uint32_t distancesMillis[360];

// Car position on the map (origin at the bottom-left corner)
double xPosition = 0;   // x position of the car (increases to the right)
double yPosition = 0;   // y position of the car (increases upwards)

// Position PID controller variables
int objectivePosition = 0;
int positionError;
int prev_positionError;
bool fixXposition = true;
bool fixInverted = true;

// Object declarations
MPU mimpu;
HardwareSerial lidarSerial(2);
RPLidar lidar;
HardwareSerial commSerial(1);
TaskHandle_t Task1;
HardwareSerial teleSerial(0);

u_int16_t distancia90;
u_int16_t distancia270;

// Declarations
int directionError(int bearing, int target);  // calculate the error in the direction

// ESP32 intercommunication functions 
void setSpeed(int speed);             // set the car's speed
void setSteering(int angle);          // set the angle of the servo
void receiveData();                   // receive data from the serial
void manageTension(uint8_t tension);  // turn a led on depending on the tension received

// LIDAR management variables
uint16_t getIndex(float angle);           // get the index in the distances array for an angle given
uint16_t readDistance(uint16_t angle);    // Angle from 0 to 359
void LidarTaskCode(void * pvParameters);  // Create code for the task which manages the LIDAR

// Send a piece of data to the telemetry esp32
void enviarDato(byte* pointer, int8_t size);
void sendPacket(byte packetType, byte* packet);

// Functions for the management of the car's position
void iteratePositionPID();    // invoke an iteration of the pid controller for the position
void turn();                  // turn
void setXcoord(uint16_t i);   // set the coordinate x axis
void setYcoord(uint16_t f);   // set the coordinate y axis
void decideTurn();            // detect the sense of turn
void checkTurn();             // check wether you have to turn or not

unsigned long marcaMillis;
byte marcaEstado;

void estadoEsperar(byte estadoObjetivo, uint16_t delay) {
  marcaMillis = millis() + delay;
  marcaEstado = estadoObjetivo;
  estado = e::Esperar;
}

void pitiditos(int num){
  while(num > 0){
    digitalWrite(pinBuzzer, HIGH);
    delay(50);
    digitalWrite(pinBuzzer,LOW);
    delay(50);
    num--;
  }
}

// ***** SETUP CODE *****
// This code will only run once, just after turning on the ESP32
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

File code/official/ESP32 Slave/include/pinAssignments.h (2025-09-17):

/***************************************************
 * 
 * THE MAIN REPOSITORY CAN BE FOUND AT https://github.com/qu4Vix/WRO-GammaVersion-2025
 * 
 * This code is under a GPL-3.0 license. More information can be found in the License file
 * in the repository.
 * 
****************************************************/

/***************************************************
 * 
 * We can find here the different pin assignments.
 * 
****************************************************/

// LED pins
#define pinLED_Azul 18
#define pinLED_Amarillo 19

// Motor Pins (PWM + 3 Digital)
#define pinPWM 14
#define pinDir1 26
#define pinDir2 27
#define pinEn 25

// Servo pins (PWM)
#define pinServo 13
#define pinServoCam 12

// Encoder pins
#define pinEncoder_CLK 32
#define pinEncoder_DT 33

// Interchip Communication pins (UART)
#define pinTX 4
#define pinRX 2

// Camera (HuskyLens) pins (I2C)
#define pinCamSDA 21
#define pinCamSCL 22

// Battery tension reader pin
#define pinVoltage 36

void setPinModes() {
    pinMode(pinVoltage, INPUT);
    pinMode(pinEncoder_DT, INPUT);
    pinMode(pinEncoder_CLK, INPUT);
    pinMode(pinLED_Azul, OUTPUT);
    pinMode(pinLED_Amarillo, OUTPUT);
}

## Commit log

2025-07-01 The 3D design of the PCB Screw Spacer
    This is the 3D design of the PCB Screw Spacer. It should be inside a "models" folder, so I ask the team meambers to reorganise this folder.
    [PCB Screw Spacer.stl]
2025-07-01 Camera's PINOUT
    This image is the camera's attachment port pinout so we can improve our documentation-
2025-07-02 Updated version of the camera's connector pinout
    I updated the camera's connector pinout after learning that the ESP32 can change its I2C ports.
    [PCB Screw Spacer.stl]
2025-07-03 ESP32 Master & Slave created
    Projects for the ESP32 Master and Slave created. Further depuration to be done.
2025-07-08 07/07/2025 update
    Code README explanation started.
    Telemetry shortened and Husky setup
    [main.cpp]
2025-07-10 Telemetry update (master)
    Error message on reboot.
    + Attempt at solving the reset problem
    [main.cpp]
2025-07-17 Thursday 17/07/2025: Main changes
    ESP32 Master:
    -Practice mode created - easy launches with no button activation.
    -Prueba state added for encoder tests
    -sendPacket added to easily send telemetry packets. Not finished- would have to add packet types for easy use and perhaps move to a telemetry library.
    -Both ESP32 reset reasons sent to telemetry on reset.
    -Work on deciding turnSense and improving the readDistance function.
    -ESP32 Communication function commented.
    ESP32 Slave:
    - Servo MIN and MAX updated due to bad positioning at start and forced ends.
    - Send reset reason to Master on reset.
    [main.cpp]
2025-07-18 Phase 1 running
    Phase 1 completed in both directions. Upgrades still to be made.
    - LEDS at the setup deleted as they were useless. Only the green light indicating button ready remains.
    - movement at speed 4 from setup
    - readDistance updated. defined the range of the measures used. Negative validIndex error removed. Lengtened (to the same amount as in 2023) the maximum time valid measures can be-which made the function work again.
    - more work into the telemetry (dataPacket struct added)
    Sending the reset reason has been temporarily desabled
    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
    [main.cpp]
2025-07-18 Reorganization
    created folders in code
    -official folder has the projects for the microcontrollers we will be using during the competition
    -extras will have the extra code we'll use during the development of the car, i.g. telemetry code or code to adjust sensors
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2025-07-29 Changes that make it work
    Not it works when doing the Open Challenge. The Distance array has been duplicated so it doens't change while we are using it. We also changed some values of the LIDAR, to make it use older values.
2025-07-30 Add Camera Testing project and improve ESP32 Slave camera logic
    Added new Camera Testing project with PlatformIO configuration, source, and documentation. Updated ESP32 Slave code to fix ENABLE_WIFI typo, add license and project comments, and refactor camera block selection logic into a dedicated function for improved clarity and maintainability.
    [main.cpp]
2025-08-21 Add 3D models and FreeCAD files for robot components
    Added STL and FreeCAD files for steering and support components, including arms, wheels, sensor supports, and PCB spacers. Also included a README describing the folder structure and purpose of the mo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
    [CameraSupport-Base.stl, CameraSupport.stl, CameraSupports.FCStd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]
2025-08-22 Telemetry update and reorganisation
    Telemetry moved from official to extras
    ESP32 Telemetry works fine so Telemetria 2.1 was removed
2025-08-22 Masters put together
    Both phases Masters put together:
    -Lidar code from phase 1 copied to phase 2.
    -Phase 2's speed system copied to phase 1
    -Removed unnecessary states
    - Added track constants to phase 1
    - Added ENABLE_TELEMETRY to phase 1
    - Practice mode added to phase 2
    - distancia 90 and 270 added to phase 2 for analytics
    - telemetry from phase 1 implemented
    - fixed issue that caused the robot to turn without entering the "Recto" state since the car wouldn't pass trough y=2400
    [main.cpp]
2025-08-24 Improve block selection logic using height/width ratio
    Added MinRatioForBlock constant and updated block selection in both Camera Testing and ESP32 Slave modules to use height/width ratio for filtering. This change helps discard line-like detections and 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
2025-08-24 Telemetry packets update
    General info packet now is packet type 6, 39 bytes long since the camera data has been moved to packet 7.
    Added millis to the general info.
    Fixed wrong decodification of the angle when it was negative.
    [main.cpp]
2025-08-24 Telemetry LIDAR millis
    Added to the telemetry the age in millis of the lidar distances for debug purposes
2025-08-26 Add repository and license headers to all source files
    Added standardized repository and GPL-3.0 license information headers to all main source and library files for both ESP32 Master and Slave projects. Improved code comments and documentation for clari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
2025-08-26 Telemetry update Master Obstacles
    Corrected the general information packet.
    [main.cpp]
2025-08-26 Telemetry camera packet
    Packet type 07 "camera data" of the telemetry added in the ESP32 Master Obstacles.
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2025-08-26 Improve HuskyLens initialization and camera block handling
    Updated serial debug message to English and added confirmation for HuskyLens connection. Set the color recognition algorithm during setup and requested learned blocks in the loop for round 2. Minor f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
2025-09-01 Revise README and add hardware design images
    The README.md was rewritten to provide a more concise and focused hardware section, emphasizing the car's steering redesign and Ackerman's Steering Geometry. Multiple hardware-related images and diagrams were added to the new 'readme-photos' directory, and the previous README was archived for reference.
2025-09-02 Created test code for unparking
    Bueno, pues hemos hecho un coso para probar la maniobr de esaparcamiento y un poco de maniobra hasta acoplar con el codigo ya existente. Nota: no funciona, hay que ver, no hecha hacia atras en ningun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
2025-09-03 02/09/2025
    1st lane exterior path adapted to avoid the parking slot.
    Idented some comments in ESP Telemetry
    [main.cpp]
2025-09-03 Updated PruebaAparcamiento
    Más pruebas e ideas, no termina de funcionar, mañana veremos a ver...
2025-09-03 Backwards motion implemented
    Slave:
    -Encoder library private function notation updated
    -Encoder library: forward bool variable created
    -UpdateEncoder function substracts when moving backwards
    -Encoder::SetMotionDirection function created to update the direction of motion
    -encoderTotal initialised at 2048 so that it stays always positive (for easier decoding)
    -Motor::SetSpeed constrain updated (0,255) -> (-255,255) so that the car can move backwards
    -In receiveData, when decoding the speed, the driving direction is updated depending on the sign of the speed received.
    Master:
    -Motion direction variable created to correct the PIDs (both the direction and the position) when moving backwards
    -Mo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
    [main.cpp]
2025-09-04 Backwards motion fully implemented
    Backwards motion changes from the ESP32 Master were added to Master Obstacles and to Prueba Aparcamiento 1
    Slight changes made to the Practice mode if
2025-09-04 Más actualizaciones del aparcamiento.
    Finalizado el desaparcamiento, y empezado el aparcamiento, le faltan unos retoques.
2025-09-05 Maniobras de aparcar y desaparcar.
    Terminado el desaparcamiento en los dos sentidos, ahora va finisimo. El aparcamiento funciona bien hacia la izquierda, hacia la derecha se para demasiado tarde en el posicionamiento, falta terminar d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
2025-09-12 Add 3D support models for robot components
    Added STL files for BackPCBSupport, CameraAndServo, and ServoCameraSupport to the robot-info/3D Designs/Supports directory. These models provide physical supports for the robot's PCB and camera/servo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
    [BackPCBSupport.stl, CameraAndServo.stl, ServoCameraSupport.stl]
2025-09-12 Union obstaculos arrancar y aparcar
    Copiado el codigo de Prueba Aparcamiento 1 al ESP Master Obstacles. Arrancar y vueltas funciona, hay que mejorar el aparcamiento.
2025-09-12 Algunos archivos freecad por si acaso, ya lgun cambio de la prueba...
    Añadido todo lo del servo de la camara en la prueba de aparcamiento...
    [Camara+Servo.FCStd, CameraAndServoGirado.stl, SoportePCBatras1.FCStd]
2025-09-12 Update README images and add new photos
    Replaced placeholder images in README.md with actual photos of the team, motor area, and LiDAR area. Added new images to the readme-photos and team-photos directories for improved documentation and team representation.
2025-09-13 13/09/2025 p1
    created autoMoveCamera to move the camera facing towards the colour blocks
    corrected error on first lane, where car avoided the blocks on the wrong lane
    added a servo for the camera, created support for this type of servo and renamed the moveservo function
    defined conversion constants for new voltage divisor
    added esp32 pinout
    work on the journal
    [main.cpp, pinAssignments.h]
2025-09-13 Small fix in main.cpp
    The offset at calculateCameraAngle had to be multiplied by turnSense to correctly counteract the angle gained while turning corners.
    [main.cpp]
2025-09-13 Update pin assignments and add buzzer feedback
    Changed buzzer and LED pin assignments for both Master and Slave ESP32 modules. Increased serial monitor speed in platformio.ini. Added buzzer feedback sequence during Master setup and ensured pinBuzzer is set as OUTPUT. Updated I2C pins for HuskyLens on Slave and commented out credentials include.
    [main.cpp, pinAssignments.h]
2025-09-13 Actualizado servo test y algo de la prueba
    Mejorada magicamente la prueba del servo, y algun cambio indeterminado en la prueba de aparacamiento :)
2025-09-16 16/09/2025 anticlockwise autoCamera working
    Master: autoMoveCamera shifted 1 tramo to match the expected block placements
    autoMoveCamera enabled only in the first lap (when blocks are detected)
    created a new atan3 fucntion which gives values from 0 to 360 to correctly deal with angles in calculateCameraAngle
    corrected calculateCameraAngle to use atan3
    commented the tramos array as it is unused
    Slave: voltage levels adapted to the new PCB
    [main.cpp]
2025-09-17 17/09/2025 autoMoveCamera working
    Reasigned battery LED pins to match the new PCB
    deactivated practice mode
    comment about speeds
    corrected camera signatures error
    move camera away from the parking lot at start and set signatures to false to avoid detecting parking lot
    parking reactivated up to posicionamiento
    desactivated slowing down on sharp turns
    beeping on block detection (causing glitch when detecting multiple times a block)
    atan3 and calculateCameraAngle modified to work anticlockwise
    autoMoveCamera switch cases shifted on anticlockwise too
    block tracking changes before getting to the middle line now to track blocks better when moving on a side lane
    blocks on the first lane are only tr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
    [main.cpp, pinAssignments.h]
2025-09-18 18/09/2025 p1
    new bool to disable camera -isRecognising-,
    function enableCamera sets isRecognising to true and sets signatures to 0
    stored the Y coordinate of the parking in case it be randomized with parkingY variable and saveParkingPosition function
    pitiditos delays reduced
    we set the default path of the first lane to be the outer, to avoid detecting the parking lot by looking away from it
    reduced the frequency of calling the automovecamera function
    when disabling the camera after the first lap, the camera is set to 0 only once, not repeteadly
    changed reposicionar to be able to check if the distance0 is measured properly
    turned camera operation off after the first tramo of the 2nd lap
    the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
    [main.cpp]
2025-09-18 Aparcar medio hecho
    Added Wait state and wait fucntion, which stops the state machine for a given amount of time and takes the machine to the next state
    KP and KD modified - positionKP was too large and the car turned too much, start kp increased for sharped turns on parking exit
    autoMoveCamera fixed for anticlockwise
    speed reduced for open challenge cruisiere speed
    [main.cpp]
2025-09-19 Final changes for the National Final
    Created alternative parking sequence "Aparcar"
    increased position kp for sharper turns
    increased kpmagico for 90 degrees turns on parking exit
    created PID enabled bool to enable or disable the position and angle PIDs to control the robot's steering mauanlly during parking
    slightly increased the x distance to the parking the car should stop at to avoid collision with it
    deleted comments in the Prueba aparcamiento
    [main.cpp]
2025-09-22 Changes from the National Final
    Increased speed during the recognition lap to avoid getting stuck.
    Increased KD and KP for better turns.
    Corrected small errors of the autoMoveCamera in the first and last tramos.
    added the praking stop Y for anticlockwise laps
    updated the LED and buzzer pins for the new PCB in the ESP32 Master
    deleted the Melody player since now we use a buzzer not a speaker
    increased the KP and KD in the Master for sharper turns
    reset reason sent at setup
    deleted debug LED and buzzer calls for the competition
    [main.cpp, pinAssignments.h]
2025-09-25 Add hardware schematics, LIDAR docs, and PCB files
    Added circuit diagrams, LIDAR datasheet and documentation, executable for LIDAR testing, and various PCB project files and images. These resources provide essential hardware documentation and referen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
2025-09-25 Update README.md
    Corrected ESP32 image
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2025-10-03 Lidar testing v2
    Added that the ransac algorithm can now detect multiple lines, and return the number of lines detected.
    Added that if the number of unassociated points is less than the concensus, the algorithm should stop.
    Created a calculate line of best fit from a sample of the data points given by an array with the indices of the points in the sample.
    Corrected error with the trigonometry in the convert to cartesian function
    Created a List class modifying a vector for its use in the ransac algorithm, where we want to exclude the inliers.
    Changed unsigned ints to uint16_t for memory efficiency.
    Added tests for the list class and added more points to the ransac test
    [lidarHandling.h, ransacAlgorithm.h]
2025-10-15 mm per encoder
    Actualizados los mm por encoder, de 1.4 a 1.517(en las dos fases). Arreglado el fallo del reseteo debido a una mala codificacion de la telemetria. Y el cambio de lo velocidad que se multiplicaba por dos.
    [main.cpp]
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2025-10-18 Fase 1 100%
    Changed UDP IP addresses in telemetry code for new network configuration. Adjusted encoder initialization and type to unsigned long, updated offset values, and fixed related calculations in both ESP32 Master and Slave code. Increased speed parameters and updated mm-per-encoder conversion factor for improved motion accuracy. Also fixed a bug in the state machine and improved position calculation logic.
    [main.cpp]
2025-10-22 RANSAC extraction completed (250ms)
    The exeRANSAC function succesfully detects wall lines even when blocks are placed. It takes around 250ms to run. We might want to change the doubles to floats for space optimisation. This is intended to be improved.
    Created a lidarDataTypes file to store the dataTypes used for the lidar management
    Added a getMeasurement function to the lidarStorage to get a measurement directly from the dataBuffer. Added also a getSize method. also added a function to set the dataArray to a given array (using memcpy)
    added a MIN SAMPLE define to reject samples too small. fused the distance2D and perpPointOnLine fro easier syntax.
    calcBestFitLineFromSample now gets a refere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
    [lidarHandling.h, main.cpp, ransacAlgorithm.h]
2025-10-24 Python telemetry viewer
    Created a telemetry manager in python that receives and displays the telemetry data. To execute it, run mainRoot.py
    There are displays for the raw data, the lidar data, the camera data, and the car's trajectory.
    There is yet work to be done. The displays are laggy, the interfaces are not polished and save button doesn't work yet.
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2025-11-01 small fix
    replaced taskdelay for task yield to switch between tasks
    commented the timer interrupts in the slave
    [main.cpp]
2025-11-01 Fix attempt
    joined both tasks in 1 task, lidar disabled with a bool variable
    [main.cpp]
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2025-11-07 Lidar Tests 07/11/2025
    Renamed the struct lidarMeasurement to a more general polarPoint2D with range and bearing.
    First attempt at spike block recognition. Check for jumps in range of consecutive readings.
    exeRANSAC now returns the unassociated points in a second return buffer of length CONCENSUS.
    platform.ini updated to fix native tests running esp32 tests too
    readDistance returns the distance for which bearing is within 5 degrees of the requested angle.
    native test function test_lidar_ransac_from_file now reads the unassociated point buffer.
    esp32 test tests the time it takes to convert the data buffer to cartesian
    [lidarHandling.h, main.cpp, ransacAlgorithm.h]
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2025-11-08 Improve encoder handling and position update logic
    Introduces mutex protection for encoder variables and refactors encoder reading/writing in the ESP32 Master Obstacles With MUTEX project. Adds a 'vueltas' counter and position update logic to the official ESP32 Master Obstacles project, improving turn handling and position correction. Updates the encoder type from unsigned long to long in the ESP32 Slave EncoderComponent for better compatibility, and adjusts encoder sending logic for more consistent timing. Also updates the UDP IP in the Telemetry decoder script.
    [main.cpp]
2025-11-08 La fumada máxima del día 8 de noviembre del 2025
    Introduced the teleEnviar() function to modularize telemetry data transmission in the ESP32 Master Obstacles code. Updated LIDAR control logic to use shorter delays and commented out some motor and enable lines for flexibility. Also adjusted battery voltage thresholds in the ESP32 Slave code for more accurate level reporting.
    [main.cpp]
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2025-11-14 Lidar measurements remodeled
    included task watchdog in case watchdog goes off.
    included some leds for debugging and a button to start the code.
    initialised the pstorage pointer to prevent null dereferences.
    added Serial prints for debugging.
    increased task stack size to prevent storage creation throwing.
    switched the lidar task to core 0.
    In Lidar Task:
    - added a lidar task delay at the beggining to prevent watchdog issues
    - taskgetstackhighwatermark added and commented as it is merely for sporadic debugging
    - added a provisional storage to store the data when reading prevents writing, and indicate the we want to load the data with the loadData bool
    - when a full measurement is carried out,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
    [lidarHandling.h, main.cpp, ransacAlgorithm.h]
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2025-11-15 Improve angle integration and position update logic
    Refactored MPU angle integration in AdvancedMPU.cpp for more accurate time-based calculation. In main.cpp, enhanced position update by incrementally integrating position changes based on angle deltas, and adjusted lidar-based position correction tolerances and timing for improved reliability. Also added delays and angle updates in position correction loops for better sensor synchronization.
    [main.cpp]
2025-11-15 Add Aparcar5 state and refine parking logic
    Introduces a new Aparcar5 state to the state machine and updates the parking maneuver logic for smoother transitions. Adjusts position increment calculations to handle direction and negative increments, and ensures steering is reset in the Final state.
    [main.cpp]
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2025-11-15 Lidar ransac test finale
    Added a getpoint function to get a point from the cartesian buffer
    Find blocks function updated to detect two consecutive close enough spikes and average their position to get a block landmark. - to be improved, 3 point blocks not handled
    added comments and prints to the ransac function
    reassigned debug pins to match the car specs
    augmented the lidar buffer size to avoid overflows
    when no startBit has been read after 500 readings, all are descarded.
    added different returns to readDistance for debugging
    added a 5 sec watchdog
    fixed error that loadData and lidarStorage where defined locally
    discard buffer when less than 6 readings have been made
    [lidarHandling.h, main.cpp, ransacAlgorithm.h]
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2025-11-15 Update vehicle photos and README, add old photos archive
    Replaced current vehicle photos with updated images and added an 'old-photos' folder to archive previous versions. Updated README.md to use direct image links and added a note about the old photos. Modified Telemetry decoder.py to update the local UDP IP and re-enable several telemetry fields in the output.
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2025-11-15 Update IMU gyro settings and telemetry handling
    Changed IMU gyro full-scale selection to G500DPS in AdvancedMPU.cpp for improved sensitivity. Disabled telemetry by default and switched serial initialization to use Serial instead of teleSerial when telemetry is off in main.cpp. Improved position update logic to use mimpu.UpdateAngle() and fixed distance reading loops for more reliable sensor data acquisition.
    [main.cpp]
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2025-11-20 Refactor obstacle and telemetry logic, update parameters
    Updated WiFi and telemetry settings, adjusted speed and parking parameters, and improved position update logic in ESP32 Master Obstacles. Enhanced reliability of position correction, removed unused function, and made minor bug fixes. Also changed gyro sensitivity in AdvancedMPU and encoder update interval in ESP32 Slave for improved performance.
    [main.cpp]
2025-11-26 International Final Day 1
    reduced maximum setSteering on open challenge
    allowed the car to avoid the first block of the final section to comply the rules
    reduced the stop angle when parking for better parallel
    correct lane on arrancar to avoid the first block always
    [main.cpp]
